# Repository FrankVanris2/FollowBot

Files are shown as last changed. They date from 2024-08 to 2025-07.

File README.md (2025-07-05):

# FollowBot

[Watch the FollowBot Prototype 1 in Action!](https://www.youtube.com/shorts/VBmE77GVLnA)

## Table of Contents
 - [Introduction](#introduction)
 - [About the Team](#about-the-team)
 - [Features](#features)
 - [Design Details](#design-details)
 - [Development Guidelines](#development-guidelines)
 - [Installation](#installation)
 - [Other Resources](#other-resources)
 - [Contributing](#contributing)
 - [License](#license)

## Introduction
Followbot is a companion robot that follows you around. The goal for this project is to build a low-cost robot that can carry you belongings for you. Currently, FollowBot is useful within school/city settings. Future endeavors include developing the capability for FollowBot to traverse uneven terrain such as dirt of gravel

## About the Team
We are a dedicated group of students committed to making robotics accessible and affordable for everyone. Our goal is to develop innovative robotic solutions that serve those in need while prioritizing safety and minimizing risks to humans. Through ethical engineering and thoughtful design, we strive to advance robotics in a way that benefits society and ensures responsible technological progress.
### Team at the Park
TeamAtThePark_1
### Close-up with the Robot
TeamCloseToRobot
### Buiding the Future

### Probem-Solving in Action


## Features
- Carry up to 50 lbs
- Mapping capabilities to traverse from one point to another
- Following mechanics
- Companion app and website to monitor and control robot remotely

## Design Details
The construction of the FollowBot presents a significant challenge, given the intricate engineering required to create a device capable of carrying and autonomously following a user. The hardware components and their assembly will demand meticulous attention and precision.

On the hardware side we are utilizing the Arduino Uno Rev4 in order to send and do important tasks for the user. We will be developing a webpage and an app with valuable information for the user to use when needed. Mapping capabilities and path-finding algorithms will be applied to the FollowBot in order to avoid obstacles while following a designated path to a specific location. Computer vision techniques will be used to allow the FollowBot to follow the user if needed in order for it to carry their belongings. Sensors such as LiDAR, RGB etc. will come with software that will allow us to really improve the machine learning models that we will apply.

In terms of project success, our primary focus will be on systematic organization and incremental prototyping. We plan to develop a prototype during the first quarter and progressively refine it. Our goal is to deliver a practical and beneficial product for any consumer seeking a FollowBot to carry their belongings or allow the FollowBot to go to designated places.

### High Level Design Architecture
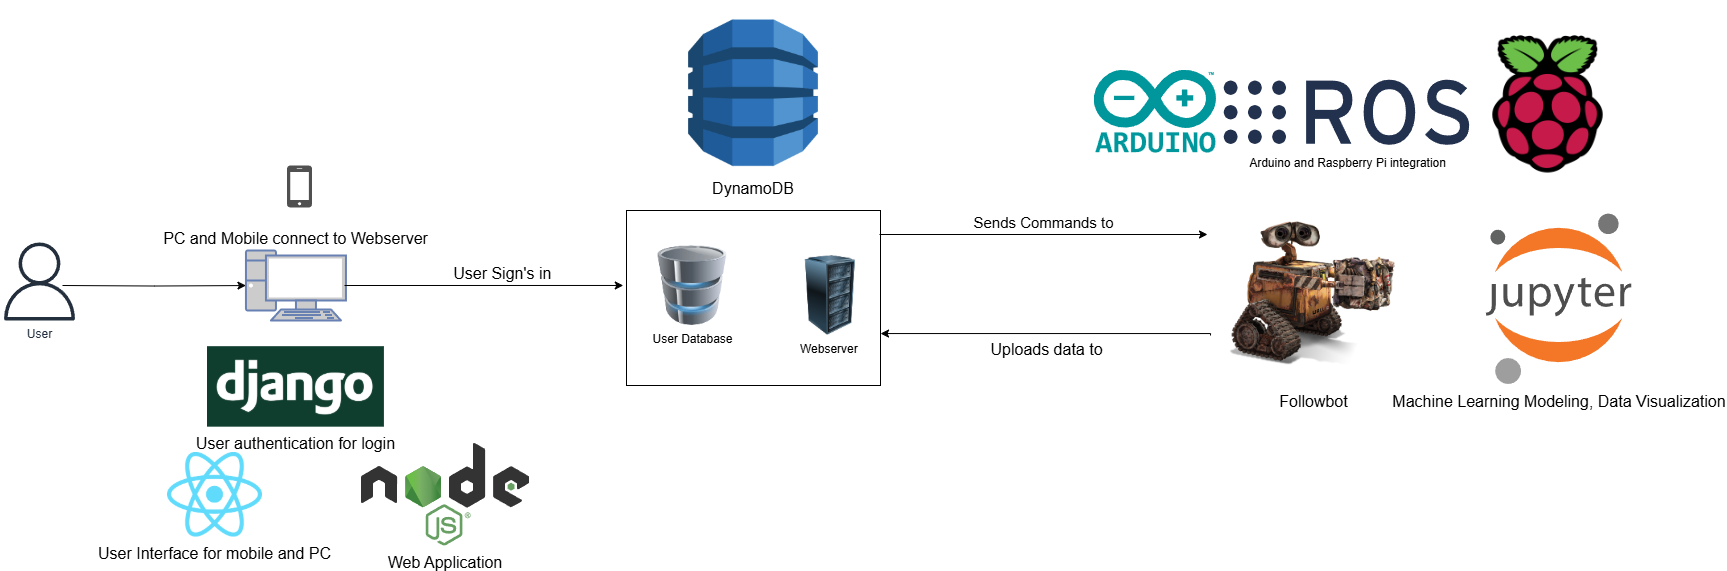
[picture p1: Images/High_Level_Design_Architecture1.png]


## Development Guidelines

### MANDATORY: Unit Testing Before Implementation

**Every developer MUST implement comprehensive unit tests before adding any new feature to the codebase, regardless of framework or repository.**

#### Testing Requirements:

1. **Write Tests First**: Follow Test-Driven Development (TDD) principles
   - Write failing tests that describe the expected behavior
   - Implement the minimum code to make tests pass
   - Refactor while keeping tests green

2. **Test Coverage Requirements**:
   - All new functions/methods must have corresponding unit tests
   - Minimum 80% code coverage for new features
   - Test both success and failure scenarios
   - Mock external dependencies (server calls, hardware interfaces)

3. **Framework-Specific Testing Standards**:
   - **Arduino/PlatformIO**: Use PlatformIO's built-in testing framework
   - **Python Backend**: Use Python's unittest or pytest
   - **JavaScript/React**: Use Jest for components and API functions
   - **C++ FollowBot Code**: Use PlatformIO native testing
   - Follow naming convention: `test_[function_name]_[scenario]`
   - Include setup and teardown for test isolation

4. **Before Pull Request**:
   ```bash
   # For Arduino/PlatformIO projects
   pio test
   
   # For Python backend
   python -m pytest
   
   # For JavaScript projects
   npm test
   
   # Verify build still works
   pio run  # For Arduino
   python -m py_compile *.py  # For Python
   npm run build  # For JavaScript
   ```

5. **Test Documentation**:
   - Document test scenarios in commit messages
   - Update test documentation when adding new test patterns
   - Reference our testing documentation: [Running Unit Tests PlatformIO](./Documentation/RunningUnitTestsPlatformIO.md)

**⚠️ CRITICAL**: No feature implementation should be merged without corresponding unit tests. This applies to all repositories in the FollowBot ecosystem, including the main robotics code, web applications, and mobile apps.

# Installation

## Installation Steps
Before you clone your repo you will need to first download vscode. The reason being is that when developing on the Robotics side There is a nice extension that is not found in any other IDE's. To make your life
easier and for you to not try and configure PlatformIO on another IDE with hassle. I would absolutely advise you to download VSCode.

* In VSCode click the extensions icon.

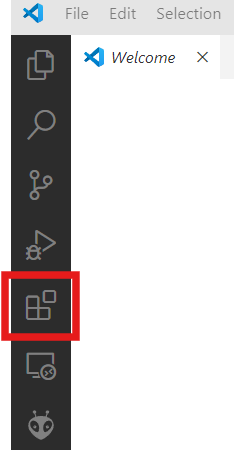
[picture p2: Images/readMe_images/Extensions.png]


* Look up **PlatformIO IDE**

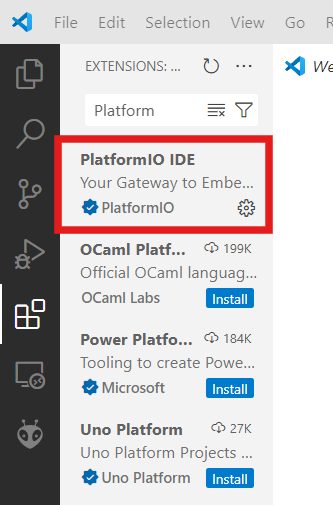
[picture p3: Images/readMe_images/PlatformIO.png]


* Install it

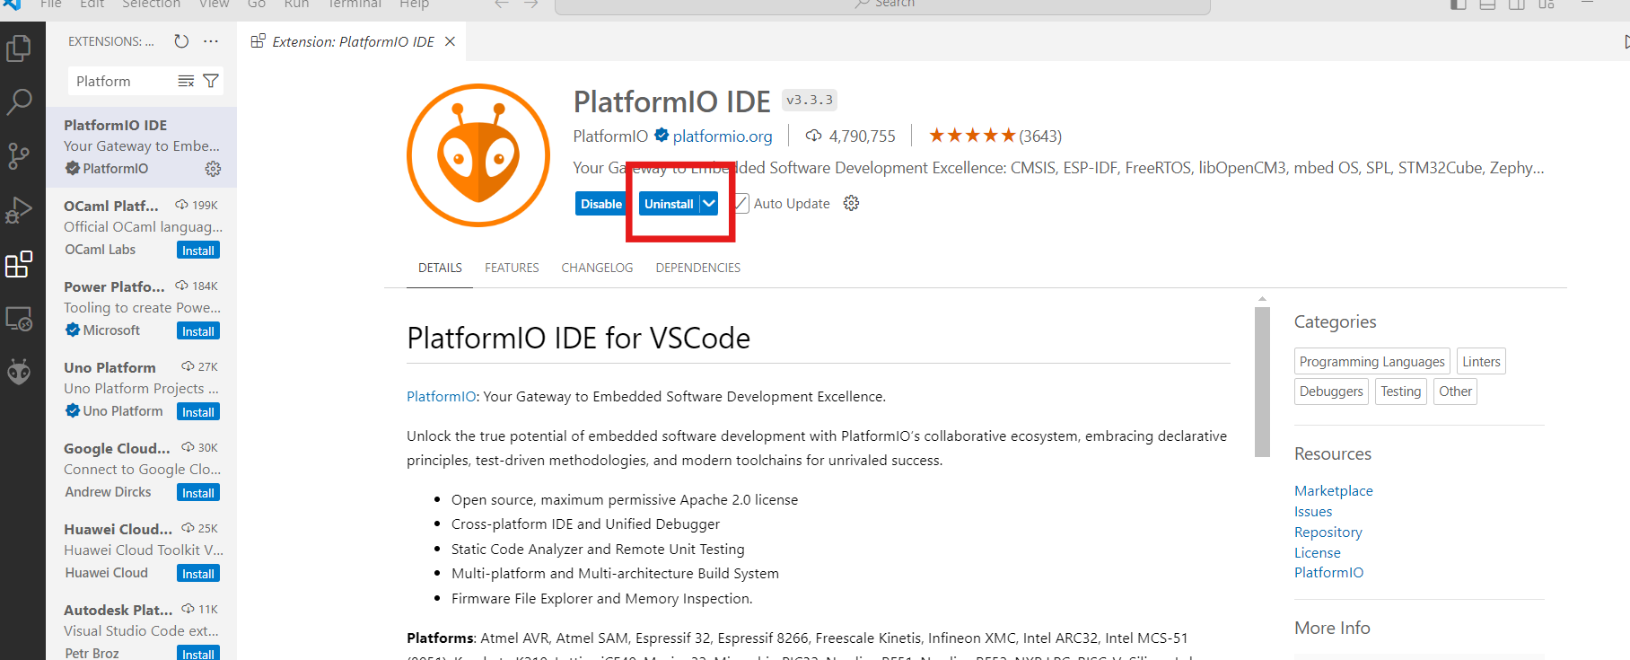
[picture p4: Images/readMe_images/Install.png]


After VSCode with the PlatformIO extension has been installed we can now git clone the repo.

## Other Resources

## Website development
The website development has been migrated to it's very own repository, same will occur for the Native React side. If you want to learn more about the website development for this project, please check out the link 
below. Many changes within this repository will continue to occur throughout our production, along with our refactoring of our project:

[Website Development for Followbot](https://github.com/FrankVanris2/FollowBotWebsite)

## Robotic-end
The robotic side of this project will involve the integration and communication between an Arduino board and a Raspberry Pi running ROS2. The Arduino board will facilitate motor and sensory communication by allowing messages to be sent back and forth, enabling various applications supported by the Raspberry Pi with ROS2. Utilizing ROS2, we can develop learning models and employ computer vision technologies to enhance the accuracy of our mapping, following mechanics, voice recognition, path-finding, and user recognition. The required steps in order to begin development on the robotic side of this project is found in the link below. It will direct you to another Repository that will connect back as always to our master repository:

[ROS2 Development for FollowBot](https://github.com/FrankVanris2/ROS2_FollowBot)

**For Arduino Development**:
* If you have not already please download VSCode with the PlatformIO extension in order for you to develop on the Robotic side.
* Within the PlatformIO homepage there are 4 side buttons that you will be allowed to click on. Please click on the `Open Project` Button

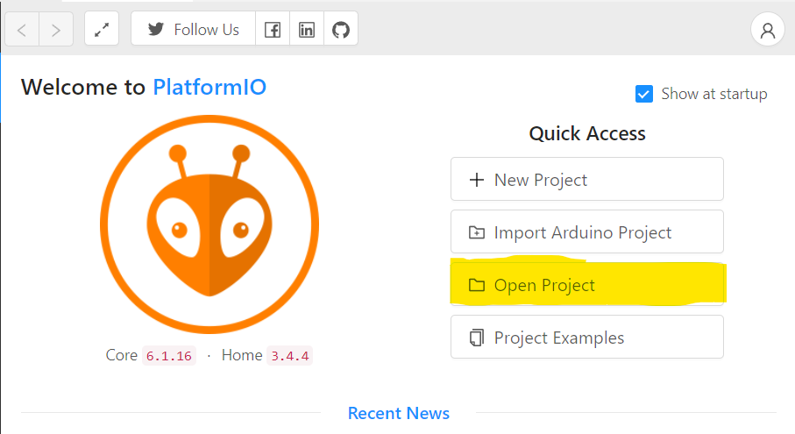
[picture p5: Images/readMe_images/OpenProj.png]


* When you do so please go where you placed your repo, and you will need to open this folder: `FollowBot->FollowBot`

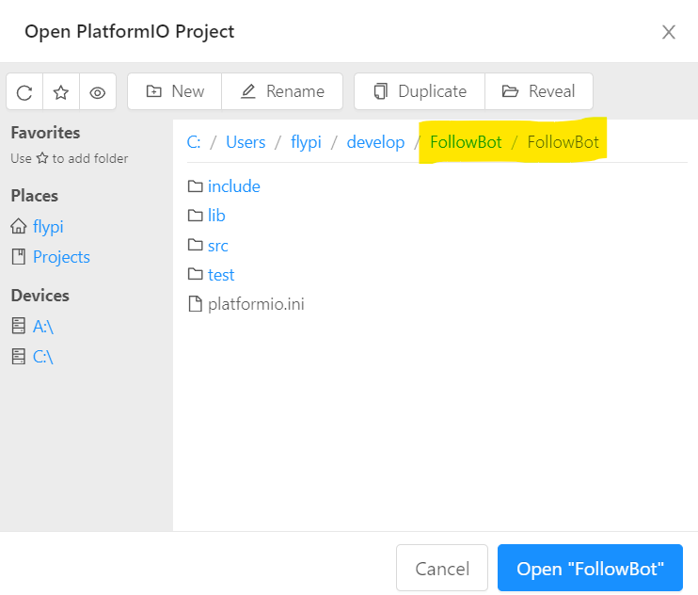
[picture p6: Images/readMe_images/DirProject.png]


* After you do so you will see all the files that we have made for the development of FollowBot.
* To run it you will need to press the blue checkmark icon at the bottom of the screen



* To push and build the code on the Arduino board or any Microcontroller that is applicable press the arrow icon at the bottom of the screen



* When you are programming on the device, sometimes you will want to print something to the Serial port. Click the plug icon to open the Serial Monitor.



* When you need to input PlatformIO specific commands, you will need to open the IO terminal. The icon is a small cmd screen.



## Other Documentation:

Within the Repo there is a directory called `Documentation` Most of the documentation is around the requirements and the design of our Project. But there is specific docs that I recommend you guys reading up on. Please read the `RunningUnitTestsPlatformIO` documentation

- [Running Unit Test PlatformIO](https://github.com/FrankVanris2/FollowBot/blob/main/Documentation/RunningUnitTestsPlatformIO.md)
  
## Contributing
We are a small team of college students, any help is appreciated! You can clone the repository on GitHub and submit a pull request.
```sh
git clone https://github.com/FrankVanris2/FollowBot.git
```

## License
MIT License 

Copyright (c) 2024 Trong Duong, Joeseph Hoang, Igor Janotti, Frank Vanris

Permission is hereby granted, free of charge, to any person obtaining a copy of this software and associated documentation files ("Followbot") to deal in the Software without restriction, including without limitation the rights to use, copy, modify, merge, publish, distribute, sublicense, and/or sell copies of the Software, and to permit persons to whom the Software is furnished to do so, subject to the following conditions:

The above copyright notice and this permission notice shall be included in all copies or substantial portions of the Software.

THE SOFTWARE IS PROVIDED “AS IS”, WITHOUT WARRANTY OF ANY KIND, EXPRESS OR IMPLIED, INCLUDING BUT NOT LIMITED TO THE WARRANTIES OF MERCHANTABILITY, FITNESS FOR A PARTICULAR PURPOSE AND NONINFRINGEMENT. IN NO EVENT SHALL THE AUTHORS OR COPYRIGHT HOLDERS BE LIABLE FOR ANY CLAIM, DAMAGES OR OTHER LIABILITY, WHETHER IN AN ACTION OF CONTRACT, TORT OR OTHERWISE, ARISING FROM, OUT OF OR IN CONNECTION WITH THE SOFTWARE OR THE USE OR OTHER DEALINGS IN THE SOFTWARE.

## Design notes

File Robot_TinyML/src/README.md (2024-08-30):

<h1>TinyML for FollowBot</h1>

Creating a tiny Machine Learning Model that will be used in order to obtain
predictions throughout the obtained historical data of battery life, distance, temperature,
and motor control.

<h2> Important mechanics </h2>

* everywhereml (used for converting learning models to cpp files for Arduino).
* tinyML offers me to use specific learning models applicable to the Arduino board.

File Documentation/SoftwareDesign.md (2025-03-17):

<h1>Software/Hardware Design Document <br>
for <br>
Follow Bot</h1>

<h2> Version 1.0 approved<br>
<br>
Prepared by Frank Vanris, Igor Janotti, Trong Duong, Joseph Hoang<br><br>
Bellevue College<br><br>
7/10/2024<br><br></h2>

<h2>
1. Introduction <br> <br>
</h2>

<h3> 1.1 Purpose<br> </h3>
This software/hardware design document describes the architecture and system design of the Follow Bot FollowBot as well as it's software, and how reliable and usable it will be for the user.<br><br>

<h3> 1.2 Scope <br> </h3>
The Goal for this FollowBot is for the user to be able to use it wherever they go while storing their belongings in a safe and reliable place. As well as map it to specific locations in order to bring items from place to place.<br><br>

<h3> 1.3 Overview <br></h3>
The main gist of this document is to explain and express how the design for this software/hardware will be handled and to explain how the user will be able to use our software and hardware efficiently and reliably.<br><br>

<h3> 1.4 Reference Material <br> </h3>
Here are the given sources that were used to relay information for this document:<br>

* https://onlinelibrary.wiley.com/doi/10.1155/2022/8274455
* https://docs.ros.org/en/jazzy/index.html
* https://docs.wpilib.org/en/stable/docs/hardware/hardware-basics/index.html
* https://docs.wpilib.org/en/stable/docs/software/hardware-apis/motors/index.html
* https://docs.arduino.cc/
* https://wiki.freecad.org/
* https://www.klipper3d.org/
* https://legacy.reactjs.org/docs/getting-started.html
* https://www.nature.com/articles/s41598-023-33837-1
* https://tinyurl.com/yc5y6r9x (AWS)
* https://scikit-learn.org/stable/ 

<h4> Books: </h4>

* Practical Robotics in C++ By *Lloyd Brombach*
* An Introduction to AI Robotics By *Robin Murphy*
* Introduction to Robotics: Mechanics and Control By *John J Craig*
* A Concise introduction to FollowBot Programming with ROS2 By *Francisco Rico Manrique*

<h3> 1.5 Definitions and Acronyms <br> </h3>

* ROS: Robotics Operating System

* DC: Direct Current

* AC: Alternating Current

* Nodes: A participant in the ROS2 Graph, which uses a client library to communicate with other nodes.

* Topics: one of the three main ways that nodes can communicate with one another is via topics.

* Jazzy: The newest version of the ROS2 of the creation of this document, there are other versions such as Jammy, Foxy, Humble, Iron, and others.

* Motor Drivers: control chips that are meant to run current through a number of motors.

* Motor Controller: Any Microcontroller that controls motors in general, such as Arduinos, ESP32's and AdaFruit controllers.

* AP: Access Points

* WiFi Triangulation: A way for wifi routers, to triangulate a position.

* Arduino: a microcontroller

* ESP32: a microcontroller
<br>

## 2. System Overview

### App

#### Goal
The goal is to have the app update you on specific features that the FollowBot contains such as battery, weight, temperature, distance, and much more. With the app you will be able to map the FollowBot to a specific location. Or call the FollowBot to come to your specific location. There are many applications that the app will bring, and much more to come after.

#### Requirements

- **Light and Dark Mode**  
  The app should support both light and dark themes for user interface customization.

- **FollowBot Mapping Feature**  
  The app will allow the FollowBot to go to a specific location, or traverse to your location.

- **FollowBot Status Updates**  
  The app will update the FollowBot's status every 30 seconds. The update will include:
  - Power level
  - Temperature
  - Weight of the FollowBot
  - Information on any movement issues related to the weight
  - Distance between the user and the FollowBot when it comes to following mechanics.

- **Distance Notifications**  
  The app will send notifications if the FollowBot gets too far away from the user.

**Damage Notifications**
 Notifications for any possible damages that occurred on the FollowBot. Such as movement control changes, Temperature unresponsive changes, weight unresponsive changes, and power unresponsive changes. As well as network unresponsive changes.

- **Controller Functionality**  
  The app will act as a controller for the FollowBots, using the touchscreen. 
  - Optionally, a game controller can be used if the touchscreen is not functional.

### Website

#### Goal
The goal of the website is to inform the users about what the FollowBot does and send queries back to the owners of the website. It will contain as well demo features that the user will be able to try out with their FollowBot. And the website will contain a forums page in order for users alike to ask questions that are related to FollowBot

#### Requirements

- **Technologies**  
  The website will be written in JavaScript, HTML, and CSS.

- **Light and Dark Mode**  
  The website will support both light and dark modes for user interface customization.

- **Pages**  
  The website will contain four main pages:
  
  1. **FollowBot**  
     - This page will include text and an embedded video from YouTube.
  
  2. **App**  
     - This page will include text, an embedded video from YouTube, and a link to download the app.
  
  3. **About Us**  
     - This page will include text and links to our work and social media profiles.
  
  4. **Feedback**  
     - This page will include a text area where users can provide feedback.
     - A private section for owners will be available to download and delete messages.
     - Consider using a database to store and manage feedback submissions.

  5. 

### Robotic Overview

#### Goal
The goal of the FollowBot is for it to carry up to 50 lbs of your belongings and follow the user while avoiding obstacles. FollowBot will also be able to map to a specific location as well as meet your specific position.

We will be experimenting with different kinds of motors, sensors, and modules to determine the best way for the FollowBot to follow the user while maneuvering through obstacles quickly. We also aim to create a device that keeps costs to a minimum, as well as find ways to have FollowBot map between two locations..
We will be experimenting with different kinds of motors, sensors, and modules to determine the best way for the FollowBot to follow the user while maneuvering through obstacles quickly. We also aim to create a device that keeps costs to a minimum.

#### Weight Carrying and Following
The user will be able to place various belongings within the device, such as food, electronics, books, sports items, clothing, and more. The FollowBot will be able to track the user based on it's 

#### Sensors
The FollowBot will use multiple sensors to avoid and move away from obstacles. Forms of avoidance will include lidar sensors, computer vision, and echo locative tracking. The choice of sensors will be decided as a team based on their accuracy in avoiding obstacles quickly.

#### Mapping
The FollowBot will be able to map out a path to a given location through API tools such as Google Maps, BC's directed Map API, and much more.
The FollowBot will use multiple sensors to avoid and move away from obstacles. Forms of avoidance will include lidar sensors, computer vision, and echo locative tracking. The choice of sensors will be decided as a team based on their accuracy in avoiding obstacles quickly.

#### Hardware
When designing the hardware, cost will be a key consideration. Initially, hardware will be created through 3D printing and simple woodworking. Designing the hardware will be done using various design applications such as FreeCAD, Fusion360, and Blender. For electronic hardware development and wiring, the final design will be created via a PCB manufacturer.

#### Real-Time Updates
Through the mobile app, the FollowBot will provide real-time updates on battery life, distance between the user and the FollowBot, the temperature within the FollowBot's capsule, and the weight distribution on the FollowBot. Notifications will be sent to the user if the battery life is low or if the FollowBot needs help or repair.

#### Machine Learning Models
We aim to add machine learning to the FollowBot. The capability for the FollowBot to learn from its mistakes through reinforcement learning could be beneficial in improving performance while conserving battery life. Our goal is to maximize battery life so the FollowBot can be used daily without frequent charging. As well as finding best possible paths to better improve the following mechanics of FollowBot.

#### Authentication/Security
We plan to add an authentication process when initializing the FollowBot on the user's account through the mobile app and the website. Each FollowBot will have a unique secure number configuration that cannot be changed. This configuration will only need to be done once.

#### Cost
We aim to keep the price range for the FollowBot under $500, ideally under $300. The device should be stable, useful, and beneficial to the consumer. The cost should attract consumers to buy our product. Our goal is to ensure the device is worth their money and to exceed their expectations.

###### UPDATE 

#### Demo GOALS
We aim to have multiple demos for FollowBot and  we consider FollowBot passing the demos as succesfully goal

### Demo 1
First demo getting information from FollowBot, 

### Demo 2
Second demo controlling the FollowBot from using website,

### Demo 3
Third demo moving circle while avoiding obsticles

<h2>3. Robotic Architecture</h2>

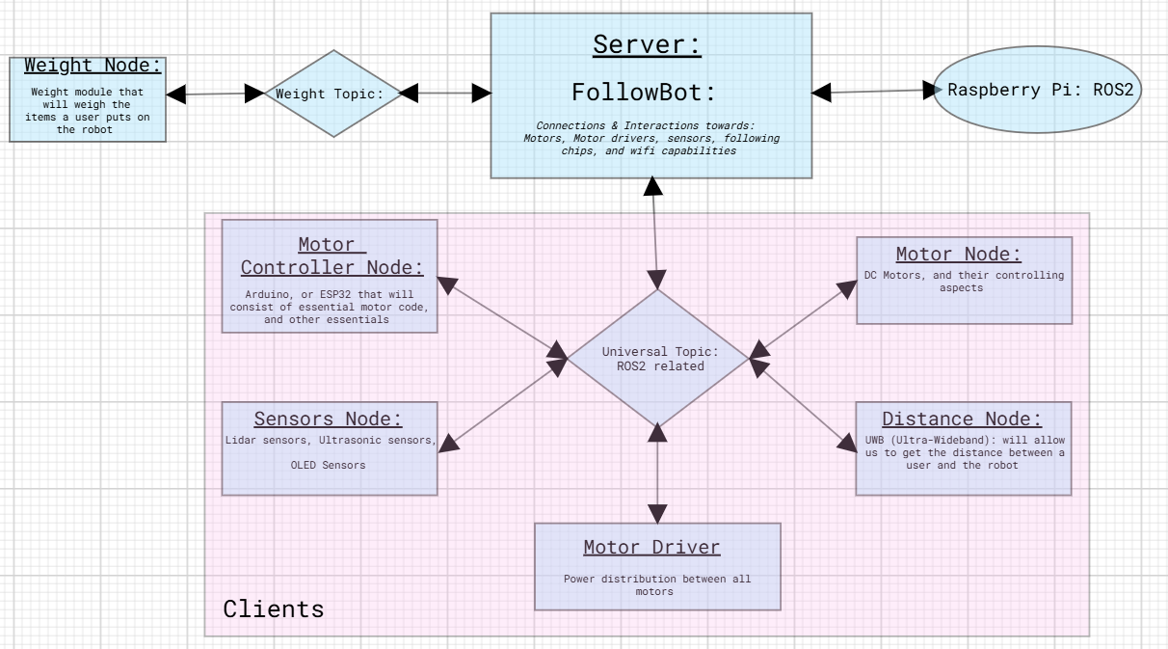
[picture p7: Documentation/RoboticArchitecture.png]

*FollowBot Architecture*

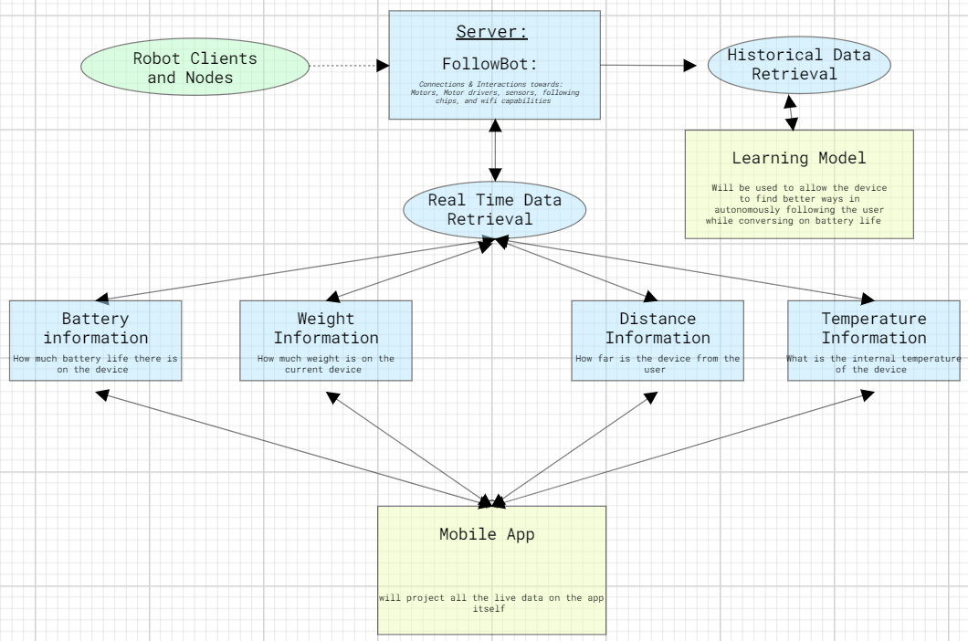
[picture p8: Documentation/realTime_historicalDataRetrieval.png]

*Data Retrieval for app and learning model*
 
 <h2>3. Systems Architecture:</h2>

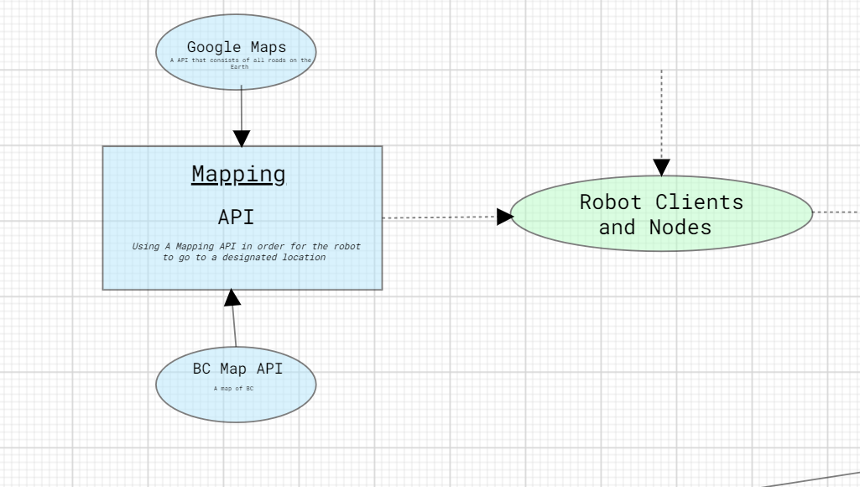
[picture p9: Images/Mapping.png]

*Mapping*

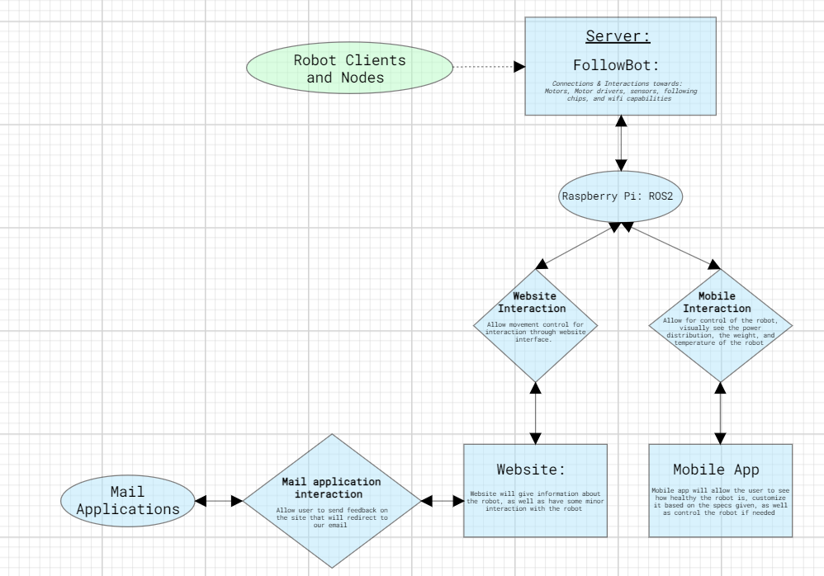
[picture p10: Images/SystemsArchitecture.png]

*Interaction between website app and FollowBot*

*Interaction between website app and FollowBot*

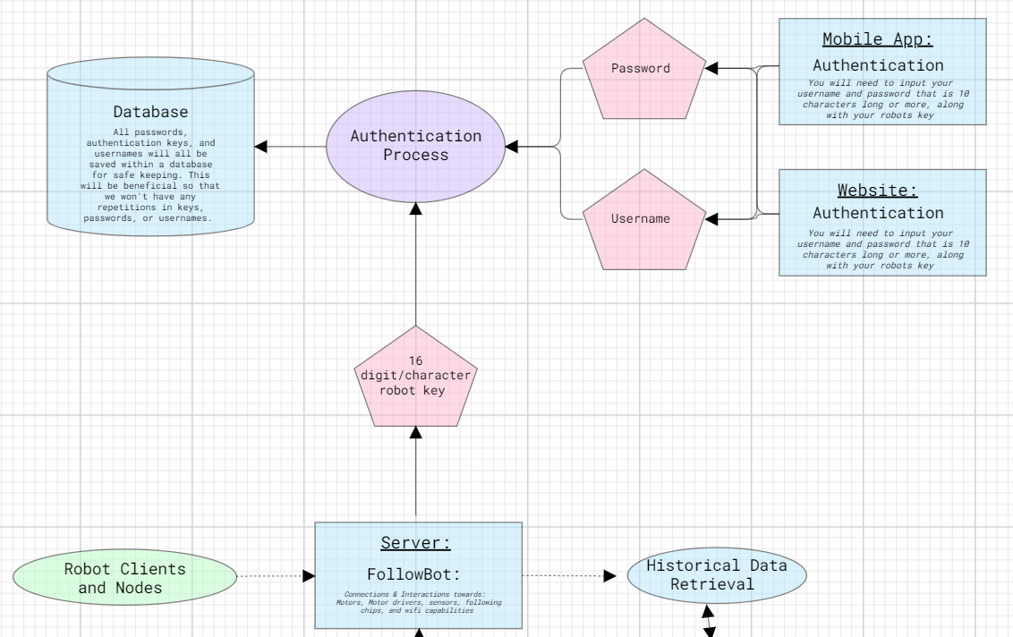
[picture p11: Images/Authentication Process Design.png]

*Authentication process for FollowBot *

*Authentication process for FollowBot*

<h2>Architectural Design for both Robotic and System sides: </h2>

<h3> FollowBot Architectural Design </h3>

<h4> 3.1 FollowBot Architecture </h4>
1. FollowBot Server:

  * FollowBot server takes place within the ROS2 Raspberry Pi.
  * allows information back and forth between client nodes.

2. Universal Topic:
    
    * Universal topic allows for message transferring and message retrieving between client and server nodes.

3. Client Nodes:

    a. Motor Controller Node:

        * Control motor movement and allow for mathematical calculations between movements between a point to another point
    
    b. Sensors Node:
        
        * Object detection, and avoidance sensors such as Lidar, supersonic
        and others. Messaging server when close to object or far from object.
    
    c. Motor Driver Node:

        * Allows control for the motors and will allow speed control for the motor controller as well as battery life control.
    
    d. Distance Node:

        * This will allow for identifying the distance between a point to another point in space.

    e. Motor Node:

        * Motor control and power supply to the motors itself.

4. External Weight Node:
    * This node is seperate from the others because this will instantly connect to the mobile device in order to give live data of how much weight is being stored on the device itself.
<br><br>

<h4>Data Retrieval and Learning Model Architecture </h4>

1. FollowBot Client:
1. FollowBot Server:

    * FollowBot client takes place in the FollowBot 
    * A python server is used to send information back and forth between the user and the FollowBot.

2. Real Time Data Retrieval:
    * A method that will be used to obtain live data from the FollowBot.
    * live data varies from battery life, to weight gain.

3. Data:
    
    **Battery Information**: Will give you how much battery is left in the system.

    **Weight Information**: Will give you the amount of weight that is being stored on the system.

    **Distance Information**: Will give the proximity and distance between you and the FollowBot.

    **Temperature Information**: Will give you the interior temperature of where you are storing your items. Will be beneficial due to the fact that people are buying groceries and do not want their items to get spoiled.

4. Mobile App:
    * Will visually show the real time data to the user when they are using the app as well as allow the user to direct itself from point A to B from a Map.
  
5. Learning Model:
    * Will be used to take in past data of the FollowBot  in order to find better ways to correct it's movement properly so it can easily, safely, and quickly follow you while trying to reduce battery consumption. 
    * Will be used to take in past data of the FollowBot in order to find better ways to correct it's movement properly so it can easily, safely, and quickly follow you while trying to reduce battery consumption.
<br><br>

<h3> 3.1 Systems Architectural Design </h3>

<h4> Mobile and Web Application Interaction </h4>

1. Server AWS:
    * We know that this will consist of all the connections to the client nodes, but it will also connect between the mobile app and the website itself.
  
2. ROS2 Raspberry Pi or Microcontroller:
    * This device consists of all the fundamental backends in order to connect to the Server which will connect to the website and mobile app. Mapping features will be also added as well.

3. Website interaction:
    * Backend to frontend interaction between the website server and FollowBot and vice versa.
    * With the website you will be able to also control the FollowBot itself by connecting to it if it is yours.

4. Website:
    * The website will consist of reliable information about the FollowBot as well as have some minor interaction with the FollowBot.

5. Mobile interaction:
    * Backend to frontend interaction between the mobile app and the Raspberry pi
    * The mobile app will have the main control over the FollowBot itself, and will display reliable information about the FollowBot

6. Mobile App:
    * You will be able to interact with the FollowBot through a mobile interface. It will allow you to see certain specs such as battery, temperature, weight, and distance. You will also be able to control the FollowBot if needed.

7. Mail Application interaction:
    * There will be an interaction from frontend to frontend for for sending information to users who have purchased FollowBot. Updates will correlate to mobile related features, FollowBot related features, and much more.

8. Mail Application:
    * The owner of the website will recieve emails from users that use the feedback page on the website. This will allow owners of the website to gain reliable information based on issues or future add-ons for the FollowBot.

9. Forums Page:
    * Users will be able to open the forums page in order to ask questions or look up questions that are related to FollowBot. Users will be able to communicate with one another, answer questions from one another, and upvote answers to questions based on how reliable they are.
  
<br><br>

<h4> Authentication Process </h4>

1. AWS Server:
1. FollowBot Server:

    * The Server will take place on a AWS instance EC2.
    * Allows information back and forth between client nodes, website, and mobile app.
    * FollowBot server takes place within the ROS2 Raspberry Pi.
    * Allows information back and forth between client nodes.

2. FollowBot  Authentication Key:
    * A 16 number/character key meant for every FolloBobot.
2. FollowBot Authentication Key:
    * A 16 number/character key meant for every FollowBot.
    * Every key will be different from the last. 

3. Mobile App/Website Authentication:
    a. You will input a username.
    b. You will input a password.

4. Authentication process:
    * the combination of the FollowBots key as well as the users password and username will allow them to be authenticated for the use of the FollowBot  and for special offers as well as access towards the guides, feedback page, and support page.
    * the combination of the FollowBots key as well as the users password and username will allow them to be authenticated for the use of the FollowBot and for special offers as well as access towards the guides, feedback page, and support page.

5. Database:
  * The database will be used to store the FollowBots keys, passwords, and usernames of users that are subscribed to the product. The database will be a way of making sure certain keys are not the same from one another as well as passwords and usernames.

<br><br>

<h4> Mapping process </h4>

1. BC Mapping API:
    * We will potentially use the BC map in order to determine the best possible path to a location for the FollowBot
    * The map will allow FollowBot to go to different locations on BC

2. Google Maps:
    * Google maps will allow for full access of mapping for the FollowBot. It will allow FollowBot to go to specific locations from point A to point B.

3. Database:
    * We will contain a Database that will potentially contain most University Campuses maps in order to traverse from point A to point B.
<br><br>

### 3.2 FollowBot Decomposition Architectural Design

#### FollowBot Architecture

1. **FollowBot Server**
    - **Description**: The FollowBot Server operates within the ROS2 Raspberry Pi and facilitates communication between client nodes.
    - **Subsystem Model**:
      - **Class**: `RobotServer`
      - **Attributes**: `serverID`, `status`
      - **Methods**: `initialize()`, `sendMessage()`, `receiveMessage()`
    - **Interface Specifications**:
      - **Interfaces**: `ICommunication`
      - **Methods**: `sendMessage()`, `receiveMessage()`
<br><br>

2. **Universal Topic**
    - **Description**: The Universal Topic enables message transfer and retrieval between client and server nodes.
    - **Subsystem Model**:
      - **Class**: `UniversalTopic`
      - **Attributes**: `topicID`, `messageQueue`
      - **Methods**: `publishMessage()`, `subscribe()`
    - **Interface Specifications**:
      - **Interfaces**: `ITopic`
      - **Methods**: `publishMessage()`, `subscribe()`
<br><br>
3. **Client Nodes**

  a. **Motor Controller Node**

  - **Description**: Controls motor movement and performs mathematical calculations for movement between points.
      
  - **Subsystem Model**:
    - **Class**: `MotorControllerNode`
    - **Attributes**: `controllerID`, `currentPosition`, `targetPosition`
    - **Methods**: `calculatePath()`, `moveToTarget()`
  - **Interface Specifications**:
    - **Interfaces**: `IMotorControl`
    - **Methods**: `calculatePath()`, `moveToTarget()`

  b. **Sensors Node**
      
  - **Description**: Handles object detection and avoidance using sensors like Lidar and supersonic sensors.
  - **Subsystem Model**:
    - **Class**: `SensorsNode`
    - **Attributes**: `sensorID`, `objectDistance`
    - **Methods**: `detectObject()`, `sendAlert()`
  - **Interface Specifications**:
    - **Interfaces**: `ISensor`
    - **Methods**: `detectObject()`, `sendAlert()`

  c. **Motor Driver Node**

  - **Description**: Controls the motors, including speed and battery life management.

  - **Subsystem Model**:
    - **Class**: `MotorDriverNode`
    - **Attributes**: `driverID`, `motorSpeed`, `batteryLevel`
    - **Methods**: `controlSpeed()`, `monitorBattery()`
  - **Interface Specifications**:
      - **Interfaces**: `IMotorDriver`
      - **Methods**: `controlSpeed()`, `monitorBattery()`

  d. **Distance Node**

  - **Description**: Identifies the distance between points in space.

  - **Subsystem Model**:
    - **Class**: `DistanceNode`
    - **Attributes**: `distanceID`, `startPoint`, `endPoint`
    - **Methods**: `calculateDistance()`
  - **Interface Specifications**:
    - **Interfaces**: `IDistance`
    - **Methods**: `calculateDistance()`

  e. **Motor Node**

  - **Description**: Manages motor control and power supply.
      
  - **Subsystem Model**:
    - **Class**: `MotorNode`
    - **Attributes**: `motorID`, `powerSupply`
    - **Methods**: `controlMotor()`
  - **Interface Specifications**:
    - **Interfaces**: `IMotor`
    - **Methods**: `controlMotor()`

  f. **External Weight Node**
    
    - **Description**: Connects to a mobile device to provide live data on the weight being stored on the device.
    - **Subsystem Model**:
      - **Class**: `ExternalWeightNode`
      - **Attributes**: `weightID`, `currentWeight`
      - **Methods**: `connectToDevice()`, `sendWeightData()`
    - **Interface Specifications**:
      - **Interfaces**: `IWeight`
      - **Methods**: `connectToDevice()`, `sendWeightData()`

<br><br>

#### Data Retrieval and Learning Model Architecture

1. **AWS Server**
    - **Description**: The FollowBot  Server operates within the AWS Instance and facilitates communication between client nodes.
1. **FollowBot Server**
    - **Description**: The FollowBot Server operates within the ROS2 Raspberry Pi and facilitates communication between client nodes.
    - **Subsystem Model**:
      - **Class**: `AWSServer`
      - **Attributes**: `serverID`, `status`
      - **Methods**: `initialize()`, `sendMessage()`, `receiveMessage()`
    - **Interface Specifications**:
      - **Interfaces**: `ICommunication`
      - **Methods**: `sendMessage()`, `receiveMessage()`

2. **Real Time Data Retrieval**
    - **Description**: A method used to obtain live data from the FollowBot. The live data varies from battery life to weight gain and more.
    - **Description**: A method used to obtain live data from the FollowBot. The live data varies from battery life to weight gain.
    - **Subsystem Model**:
      - **Class**: `RealTimeDataRetrieval`
      - **Attributes**: `dataID`, `batteryLife`, `weightGain`, `timestamp`
      - **Methods**: `retrieveBatteryLife()`, `retrieveWeightGain()`, `updateTimestamp()`
    - **Interface Specifications**:
      - **Interfaces**: `IDataRetrieval`
      - **Methods**: `retrieveBatteryLife()`, `retrieveWeightGain()`, `updateTimestamp()`

3. **Data**
    - **Description**: Provides various types of information about the FollowBot.
    - **Subsystem Model**:
      - **Class**: `Data`
      - **Attributes**: `batteryInfo`, `weightInfo`, `distanceInfo`, `temperatureInfo`
      - **Methods**: `getBatteryInfo()`, `getWeightInfo()`, `getDistanceInfo()`, `getTemperatureInfo()`
    - **Interface Specifications**:
      - **Interfaces**: `IData`
      - **Methods**: `getBatteryInfo()`, `getWeightInfo()`, `getDistanceInfo()`, `getTemperatureInfo()`

4. **Mobile App**
    - **Description**: Visually shows the real-time data to the user when they are using the app.
    - **Subsystem Model**:
      - **Class**: `MobileApp`
      - **Attributes**: `appID`, `realTimeData`
      - **Methods**: `displayRealTimeData()`
    - **Interface Specifications**:
      - **Interfaces**: `IMobileApp`
      - **Methods**: `displayRealTimeData()`

5. **Learning Model**
    - **Description**: Takes in past data of the FollowBot to find better ways to correct its movement, ensuring it can follow you easily, safely, and quickly while reducing battery consumption.
    - **Subsystem Model**:
      - **Class**: `LearningModel`
      - **Attributes**: `modelID`, `pastData`
      - **Methods**: `analyzeData()`, `optimizeMovement()`
    - **Interface Specifications**:
      - **Interfaces**: `ILearningModel`
      - **Methods**: `analyzeData()`, `optimizeMovement()`

6. **Mapping**
    - **Description**: Allows FollowBot to go from point A to point B from a Map that is saved on the Database.
    - **Subsystem Model**:
      - **Class**: `Mapping`
      - **Attributes**: `mappingID`, `mapData`
      - **Methods**: `obtainMap()`, `obtainMapPositionA()`, `obtainMapPositionB()`
    - **Interface Specifications**:
      - **Interface**: `IMapping`
      - **Methods**: `obtainMap()`, `obtainMapPositionA()`, `obtainMapPositionB()`

### 3.2 Systems Decomposition Architectural Design

#### Mobile and Web Application Interaction

1. **Server AWS**
    - **Description**: Consists of all the connections to the client nodes and connects the mobile app and the website.
    - **Subsystem Model**:
      - **Class**: `ServerAWS`
      - **Attributes**: `awsID`, `status`
      - **Methods**: `connectToClientNodes()`, `connectToMobileApp()`, `connectToWebsite()`
    - **Interface Specifications**:
      - **Interfaces**: `IConnection`
      - **Methods**: `connectToClientNodes()`, `connectToMobileApp()`, `connectToWebsite()`

2. **ROS2 Raspberry Pi Or Microcontroller**
    - **Description**: Contains all the fundamental backends to connect to the website and the mobile app.
    - **Subsystem Model**:
      - **Class**: `ROS2RaspberryPi`or `Arduino`
      - **Attributes**: `deviceID`, `backendStatus`
      - **Methods**: `initializeBackend()`, `connectToWebsite()`, `connectToMobileApp()`
    - **Interface Specifications**:
      - **Interfaces**: `IBackend`
      - **Methods**: `initializeBackend()`, `connectToWebsite()`, `connectToMobileApp()`

3. **Website Interaction**
    - **Description**: Backend to frontend interaction between the website to server to Raspberry Pi or Microcontroller. Allows control of the FollowBot if nearby.
    - **Description**: Backend to frontend interaction between the website and the Raspberry Pi. Allows control of the FollowBot if nearby.
    - **Subsystem Model**:
      - **Class**: `WebsiteInteraction`
      - **Attributes**: `interactionID`, `websiteStatus`
      - **Methods**: `backendToFrontend()`, `controlRobot()`
    - **Interface Specifications**:
      - **Interfaces**: `IWebsiteInteraction`
      - **Methods**: `backendToFrontend()`, `controlRobot()`

4. **Website**
    - **Description**: Provides reliable information about the FollowBot and allows minor interaction with the FollowBot.
    - **Subsystem Model**:
      - **Class**: `Website`
      - **Attributes**: `websiteID`, `content`
      - **Methods**: `displayInfo()`, `interactWithRobot()`
    - **Interface Specifications**:
      - **Interfaces**: `IWebsite`
      - **Methods**: `displayInfo()`, `interactWithRobot()`

5. **Mobile Interaction**
    - **Description**: Backend to frontend interaction between the mobile app, server and the Raspberry Pi or Microcontroller. The mobile app has main control over the FollowBot.
    - **Subsystem Model**:
      - **Class**: `MobileInteraction`
      - **Attributes**: `interactionID`, `mobileStatus`
      - **Methods**: `backendToFrontend()`, `controlRobot()`
    - **Interface Specifications**:
      - **Interfaces**: `IMobileInteraction`
      - **Methods**: `backendToFrontend()`, `controlRobot()`

6. **Mobile App**
    - **Description**: Allows interaction with the FollowBot through a mobile interface. Displays specs like battery, temperature, weight, and distance. Allows control of the FollowBot.
    - **Subsystem Model**:
      - **Class**: `MobileApp`
      - **Attributes**: `appID`, `specs`
      - **Methods**: `displaySpecs()`, `controlRobot()`
    - **Interface Specifications**:
      - **Interfaces**: `IMobileApp`
      - **Methods**: `displaySpecs()`, `controlRobot()`

7. **Mail Application Interaction**
    - **Description**: Frontend to frontend interaction for sending messages through email to the website owner.
    - **Subsystem Model**:
      - **Class**: `MailAppInteraction`
      - **Attributes**: `interactionID`, `emailStatus`
      - **Methods**: `sendEmail()`
    - **Interface Specifications**:
      - **Interfaces**: `IMailInteraction`
      - **Methods**: `sendMail()`

8. **Mail Application**
    - **Description**: The website owner receives emails from users using the feedback page. Provides reliable information based on issues or future add-ons for the FollowBot.
    - **Subsystem Model**:
      - **Class**: `MailApplication`
      - **Attributes**: `mailID`, `feedback`
      - **Methods**: `receiveEmail()`, `processFeedback()`
    - **Interface Specifications**:
      - **Interfaces**: `IMailApplication`
      - **Methods**: `recieveEmail()`, `processFeedback()`

#### Authentication Process

1. **FollowBot Authentication Key**
    - **Description**: A 16 number/character key meant for every FollowBot. Every key will be different from the last.
    - **Subsystem Model**:
      - **Class**: `RobotAuthKey`
      - **Attributes**: `keyID`, `keyValue`
      - **Methods**: `generateKey()`, `validateKey()`
    - **Interface Specifications**:
      - **Interfaces**: `IAuthKey`
      - **Methods**: `generateKey()`, `validateKey()`

2. **Mobile App/Website Authentication**
    - **Description**: Authentication process involving username and password input.
    - **Subsystem Model**:
      - **Class**: `AuthProcess`
      - **Attributes**: `username`, `password`
      - **Methods**: `inputUsername()`, `inputPassword()`
    - **Interface Specifications**:
      - **Interfaces**: `IAuthProcess`
      - **Methods**: `inputUsername()`, `inputPassword()`

3. **Authentication Process**
    - **Description**: Combines the FollowBot’s key with the user’s password and username for authentication.
    - **Subsystem Model**:
      - **Class**: `Authentication`
      - **Attributes**: `authID`, `robotKey`, `userCredentials()`
      - **Methods**: `authenticateUser()`, `grantAccess()`
    - **Interface Specifications**:
      - **Interfaces**: `IAuthentication`
      - **Methods**: `authenticateUser()`, `grantAccess()`

3. **Database**
    - **Description**: Stores FollowBot keys, passwords, and usernames of users subscribed to the product. Ensures unique keys, passwords, and usernames.
    - **Description**: Stores FollowBot keys, passwords, and usernames of users subscribed to the product. Ensures unique keys, passwords, and usernames.
    - **Subsystem Model**:
      - **Class**: `Databse`
      - **Attributes**: `dbID`, `userData`
      - **Methods**: `storeData()`, `retrieveData()`
    - **Interface Specifications**:
      - **Interfaces**: `IDatabase`
      - **Methods**: `storeData()`, `retrieveData()`

#### Mapping Process

1. **BC Mapping API**
    - **Description**: We will potentially use the BC map to determine the best possible path to a location for the FollowBot.
    - **Subsystem Model**:
        - **Class**: `BCMappingAPI`
        - **Attributes**: `mapData`, `locationPoints`
        - **Methods**: `getOptimalPath()`, `navigateToLocation()`
    - **Interface Specifications**:
        - **Interfaces**: `IMappingAPI`
        - **Methods**: `getOptimalPath()`, `navigateToLocation()`

2. **Google Maps**
    - **Description**: Google Maps will allow for full access to mapping for the FollowBot. It will enable FollowBot to go to specific locations from point A to point B.
    - **Subsystem Model**:
        - **Class**: `GoogleMapsAPI`
        - **Attributes**: `startPoint`, `endPoint`
        - **Methods**: `getDirections()`, `calculateRoute()`
    - **Interface Specifications**:
        - **Interfaces**: `IMappingAPI`
        - **Methods**: `getDirections()`, `calculateRoute()`

3. **Database**
    - **Description**: A Database that will potentially contain most University Campuses' maps to traverse from point A to point B.
    - **Subsystem Model**:
        - **Class**: `CampusMapDatabase`
        - **Attributes**: `campusMapData`, `mapID`
        - **Methods**: `storeMap()`, `retrieveMap()`
    - **Interface Specifications**:
        - **Interfaces**: `IDatabase`
        - **Methods**: `storeMap()`

<h2> 3.3 Design Rationale </h2>
We chose this architecture because we needed something modulus in order to do things properly for the scope of our project. When it comes to the authentication process it was tedious in knowing how we would come about it, but we knew that if we made it modular it would make it less tedious in our side. The way we did it is by creating a Database that the authenticator would interact with in order to generate keys for the FollowBot that would not create replicas based on the ones that are currently on the database. That was one rationale that we chose for this project. 
<br><br>
Another is by keeping the ros2 system on the raspberry pi very interactive between many different pieces of hardware and software. With the ROS2 most of the functionalities that will be introduced will always have to be modulus in order for us to communicate between many different areas of hardware and software. Although we've been consistently using a Microcontroller so switching between the two will depend based on how much modular this project will become. No doubt it will become more modular based on the number of components we will be adding.
<br><br>
We also need to rely on the learning models and the mapping api's in order to see the improvements in following within FollowBot. We will also need to getting the Mapping algorithm working accordingly with the FollowBot  which is keeping an eye on it's surroundings.
<br><br>
The way we structured our decomposition above makes it easier for us to understand how we will simplify yet comprehend how our system should be.

<h2> 4.0 Data Design </h2>

<h3> 4.1 Data Description </h3>
When it comes to data and obtaining historical data for the machine learning model we will be using dataframes in order to store the data properly, ranging from battery life to weight distribution. When it comes to Databases the information will also be stored in a table of data. Other forms of data storing will be used in other applications when it comes to the FollowBot itself

<h3> 4.2 Data Dictionary </h3>

| Object|Attributes|Methods|
|---|---|---|
| **Authentication**| `authID`: String,<br> `robotKey`: String,<br> `userCredentials`: Object| `authenticateUser()`,<br>`grantAccess()`|
| **AuthProcess**| `username`: String,<br> `password`: String| `inputUsername()`,<br> `inputPassword()`|
| **Data**| `batteryInfo`: Float,<br> `weightInfo`: Float,<br> `distanceInfo`: Float,<br> `temperatureInfo`: Float| `getBatteryInfo()`,<br> `getWeightInfo()`,<br> `getDistanceInfo()`,<br> `getTemperatureInfo()`|
| **Database**| `dbID`: String,<br> `userData`: Object| `storeData()`,<br> `retrieveData()`|
| **DistanceNode**| `distanceID`: String,<br> `startPoint`: Object,<br> `endPoint`: Object| `calculateDistance()`|
| **ExternalWeightNode**| `weightID`: String,<br> `currentWeight`: Float| `connectToDevice()`,<br> `sendWeightData()`|
| **LearningModel**| `modelID`: String,<br> `pastData`: Object| `analyzeData()`,<br> `optimizeMovement()`|
| **MailAppInteraction**| `interactionID`: String,<br> `emailStatus`: String| `sendEmail()`|
| **MailApplication**| `mailID`: String,<br> `feedback`: Object| `receiveEmail()`,<br> `processFeedback()`|
| **MobileApp**| `appID`: String,<br> `specs`: Object| `displaySpecs()`,<br> `controlRobot()`|
| **MobileInteraction**| `interactionID`: String,<br> `mobileStatus`: String| `backendToFrontend()`,<br> `controlRobot()`|
| **MotorControllerNode**| `controllerID`: String,<br> `currentPosition`: Object,<br> `targetPosition`: Object | `calculatePath()`,<br> `moveToTarget()`|
| **MotorDriverNode**| `driverID`: String,<br> `motorSpeed`: Float,<br> `batteryLevel`: Float| `controlSpeed()`,<br> `monitorBattery()`|
| **MotorNode**| `motorID`: String,<br> `powerSupply`: Float| `controlMotor()`|
| **RealTimeDataRetrieval**| `dataID`: String,<br> `batteryLife`: Float,<br> `weightGain`: Float,<br> `timestamp`: DateTime| `retrieveBatteryLife()`,<br> `retrieveWeightGain()`,<br> `updateTimestamp()`|
| **FollowBottAuthKey**| `keyID`: String,<br> `keyValue`: String| `generateKey()`,<br> `validateKey()`|
| **AWSServer**| `serverID`: String,<br> `status`: String| `initialize()`,<br> `sendMessage()`,<br> `receiveMessage()`|
| **SensorsNode**| `sensorID`: String,<br> `objectDistance`: Float| `detectObject()`,<br> `sendAlert()`|
| **ServerAWS**| `serverID`: String,<br> `status`: String| `connectToClientNodes()`,<br> `connectToMobileApp()`,<br> `connectToWebsite()`|
| **UniversalTopic**| `topicID`: String,<br> `messageQueue`: Queue| `publishMessage()`,<br> `subscribe()`|
| **Website**| `websiteID`: String,<br> `content`: String| `displayInfo()`,<br> `interactWithRobot()`|
| **WebsiteInteraction**| `interactionID`: String,<br> `websiteStatus`: String| `backendToFrontend()`,<br> `controlRobot()`|

<h2> 5. Component Design </h2>

#### Authentication
- **authenticateUser()**
  - Input: `robotKey`, `userCredentials`
  - Process: Validate `robotKey` and `userCredentials`
  - Output: Authentication status

- **grantAccess()**
  - Input: Authentication status
  - Process: Check if authentication is successful
  - Output: Access granted or denied

#### AuthProcess
- **inputUsername()**
  - Input: `username`
  - Process: Store `username`
  - Output: get access to your account once password is in

- **inputPassword()**
  - Input: `password`
  - Process: Store `password`
  - Output: get access to your account

#### Data
- **getBatteryInfo()**
  - Input: Battery potentiometer counter
  - Process: Retrieve `batteryInfo`
  - Output: `batteryInfo`

- **getWeightInfo()**
  - Input: Weight measurer module
  - Process: Retrieve `weightInfo`
  - Output: `weightInfo`

- **getDistanceInfo()**
  - Input: UWB, Bluetooth, or GPS
  - Process: Retrieve `distanceInfo`
  - Output: `distanceInfo`

- **getTemperatureInfo()**
  - Input: Temperature module
  - Process: Retrieve `temperatureInfo`
  - Output: `temperatureInfo`

#### Database
- **storeData()**
  - Input: `userData`
  - Process: Store `userData` in database
  - Output: None

- **retrieveData()**
  - Input: Query
  - Process: Retrieve data from database
  - Output: `userData`

#### DistanceNode
- **calculateDistance()**
  - Input: `startPoint`, `endPoint`
  - Process: Calculate distance between `startPoint` and `endPoint`
  - Output: Distance

#### ExternalWeightNode
- **connectToDevice()**
  - Input: Device ID
  - Process: Establish connection to device
  - Output: Connection status

- **sendWeightData()**
  - Input: `currentWeight`
  - Process: Send `currentWeight` to device
  - Output: None

#### LearningModel
- **analyzeData()**
  - Input: `pastData`
  - Process: Analyze `pastData`
  - Output: Analysis results

- **optimizeMovement()**
  - Input: Analysis results
  - Process: Optimize FollowBot movement
  - Output: Optimized movement parameters

#### MailAppInteraction
- **sendEmail()**
  - Input: Email content
  - Process: Send email to website owner
  - Output: Owner recieves email from users message input

#### MailApplication
- **receiveEmail()**
  - Input: None
  - Process: Receive email from users
  - Output: Email content

- **processFeedback()**
  - Input: Email content
  - Process: Analyze feedback
  - Output: Feedback analysis

#### MobileApp
- **displaySpecs()**
  - Input: `specs`
  - Process: Display `specs` on mobile app
  - Output: None

- **controlFollowBot()**
  - Input: Control commands
  - Process: Send control commands to FollowBot
  - Output: FollowBot could move or follow a set of tasks

#### MobileInteraction
- **backendToFrontend()**
  - Input: Backend data
  - Process: Transfer data to frontend
  - Output: Data transfer successful or not

- **controlFollowBot()**
  - Input: Control commands
  - Process: Send control commands to FollowBot
  - Output: FollowBot executes those commands

#### MotorControllerNode
- **calculatePath()**
  - Input: `currentPosition`, `targetPosition`
  - Process: Calculate path from `currentPosition` to `targetPosition`
  - Output: Path

- **moveToTarget()**
  - Input: Path
  - Process: Move motor along path
  - Output: motor turns on in order to move towards target

#### MotorDriverNode
- **controlSpeed()**
  - Input: Speed value
  - Process: Adjust motor speed
  - Output: motors speed is adjusted

- **monitorBattery()**
  - Input: Battery potentiometer reading
  - Process: Monitor battery level
  - Output: `batteryLevel`

#### MotorNode
- **controlMotor()**
  - Input: Control commands
  - Process: Execute motor control commands
  - Output: motor commands are executed

#### RealTimeDataRetrieval
- **retrieveBatteryLife()**
  - Input: Battery potentiometer current data reading
  - Process: Retrieve current battery life
  - Output: `batteryLife`

- **retrieveWeightGain()**
  - Input: Weight Module
  - Process: Retrieve current weight gain
  - Output: `weightGain`

- **updateTimestamp()**
  - Input: None
  - Process: Update timestamp of data retrieval
  - Output: `timestamp`

#### FollowBotAuthKey
- **generateKey()**
  - Input: None
  - Process: Generate a new authentication key
  - Output: `keyValue`

- **validateKey()**
  - Input: `keyValue`
  - Process: Validate the authentication key
  - Output: Validation status

#### AWSServer
- **initialize()**
  - Input: None
  - Process: Initialize the FollowBot server
  - Output: Initialization status

- **sendMessage()**
  - Input: Message
  - Process: Send message to client nodes
  - Output: nodes recieves message

- **receiveMessage()**
  - Input: None
  - Process: Receive message from client nodes
  - Output: Message

#### SensorsNode
- **detectObject()**
  - Input: Lidar sensors, light sensors, etc.
  - Process: Detect object using sensors
  - Output: Object detection status

- **sendAlert()**
  - Input: Object detection status
  - Process: Send alert when object is detected
  - Output: Stop or avoid obstacle when object is detected

#### ServerAWS
- **connectToClientNodes()**
  - Input: None
  - Process: Connect to client nodes
  - Output: Connection status

- **connectToMobileApp()**
  - Input: None
  - Process: Connect to mobile app
  - Output: Connection status

- **connectToWebsite()**
  - Input: None
  - Process: Connect to website
  - Output: Connection status

#### UniversalTopic
- **publishMessage()**
  - Input: Message
  - Process: Publish message to topic
  - Output: None

- **subscribe()**
  - Input: None
  - Process: Subscribe to topic
  - Output: Subscription status

#### Website
- **displayInfo()**
  - Input: Information
  - Process: Display information about the FollowBot
  - Output: information of FollowBot is displayed

- **interactWithFollowBot()**
  - Input: Interaction commands
  - Process: Execute interaction commands with the FollowBot
  - Output: interaction command is executed

#### WebsiteInteraction
- **backendToFrontend()**
  - Input: Backend data
  - Process: Transfer data to frontend
  - Output: None

- **controlRFollowBot()**
  - Input: Control commands
  - Process: Send control commands to FollowBot
  - Output: control command is executed

#### Mapping Process

1. **BC Mapping API**
    - **getOptimalPath()**
        - **Input**: `currentLocation`, `destination`
        - **Process**: Calculate the best possible path from `currentLocation` to `destination` using BC map data.
        - **Output**: Optimal path as a list of coordinates
    - **navigateToLocation()**
        - **Input**: `targetLocation`
        - **Process**: Navigate FollowBot to the target location based on the optimal path.
        - **Output**: Success or failure status

2. **Google Maps**
    - **getDirections()**
        - **Input**: `startPoint`, `endPoint`
        - **Process**: Retrieve directions from Google Maps for the specified route.
        - **Output**: Directions as a list of coordinates
    - **calculateRoute()**
        - **Input**: `startPoint`, `endPoint`
        - **Process**: Calculate the route from `startPoint` to `endPoint` using Google Maps.
        - **Output**: Calculated route as a list of coordinates

3. **Database**
    - **storeMap()**
        - **Input**: `mapData`
        - **Process**: Store campus maps in the database.
        - **Output**: Success or failure status
    - **retrieveMap()**
        - **Input**: `mapID`
        - **Process**: Retrieve the map for a given campus.
        - **Output**

<h2> 6. Human Interface Design </h2>

<h3> Mobile App: </h3>
As a user when it comes to both the mobile application, it will contain most of the major functionalities. For instance with the mobile app you will be able to see how much battery life is currently on the system, as well as how much weight, the current distance it is away from you, as well as the interior temperature. With the mobile app you will be able to as well interact with the device by controlling its movement if needed. You will be able to test given features with it. Look at the specs of the FollowBot, as well as look at the health of the FollowBot. Parts and services will also be shown of the application itself. The app will be able to as well send you notifications based on how much health is currently on the system, whether if the FollowBot ran into some issues, or is in need of assistance. You as a user will be able to use the app throughout many different mobile devices ranging from apple to android. 
<br><br>

#### Important Functionalities 
Visually on the top right corner of the screen will indicate the battery life of your FollowBot. The middle of the screen will consist of a 3d model version of the FollowBot, while beneath the FollowBot will indicate the amount of weight that is currently on the system. In the middle above the FollowBot will indicate the current temperature within the interior of the FollowBot. A small tab button on the bottom right corner will allow the user to see how far away the FollowBot is from the user. 
<br><br>

#### Settings
on the top left corner will be a setting icon for the FollowBot, where you will be able to find the specs of the FollowBot, changing capabilities for when you want to change the distance between you and the FollowBot, as well as the ability to switch on human control access towards the FollowBot. When switching on human access within the mobile app, the ui will change to a control panel where you will now be able to control the FollowBot through touch screen.

#### Authentication
When accessing the app it will first bring you to an authenticator screen, where you will need to input your username or password . If the user is signing in for the first time then they'll also need to input the FollowBots authentication key in order to access their specific FollowBot that they purchased, as well as their email. However once they do it the first time they won't need to do it again. As a user you will be able to change your password, or username if you forgot. In order to do so, an email will be sent to the user in which they will have to confirm or not that they want a change for a new username or password.

### Website: 
As for the website, it will have minor interactions with the user. But for the user, the website will offer another variety of options that is quite different compared to the mobile app. For instance, the web interface will consist of a variety of tabs to open and see. One tab will consist of a feedback page/guide where you as the user that is currently an owner of the device will be able to ask questions or discuss topics based on the robotic device that you have on hand. Questions can vary from hardware parts, to ways in keeping the FollowBot clean, updating its software, or even future changes in parts for the FollowBot. 
<br><br>

#### Relevant tabs for user to go about
Other tabs will consists of information of the FollowBot, as well as a video recording in how the FollowBot interacts with it's surroundings. Another tab will be accessible to owners of the FollowBot where they will be able to interact with their FollowBot and see how well it's able to avoid obstacles while being able to follow a coordinated path. You will be able to control the FollowBot with this minor interaction that will be found on the web page.
<br><br>

#### News Posting
Another important feature that we would like to add is a news posting tab,
where people will be able to get notified in future updates based on the FollowBots development progress, or even updates on future releases for the FollowBot itself, such as enhancements in parts or software.

#### Authentication
As mentioned within the Mobile App user interface, it will be the same. However the difference will be that you don't have to sign in immediately, The webpage is meant for informational purposes. If you wish to create an account or sign in. A user profile icon for that will be found above in the right hand corner of your screen.

#### Mapping
ON the Mobile app there will be a mapping interface where you will be able to obtain the location of the FollowBot and pinpoint it to a new location. Either to you or to a point of interest. It will give you the estimated time for it to travel there.

### 6.2 Screen Images

#### Mobile App:
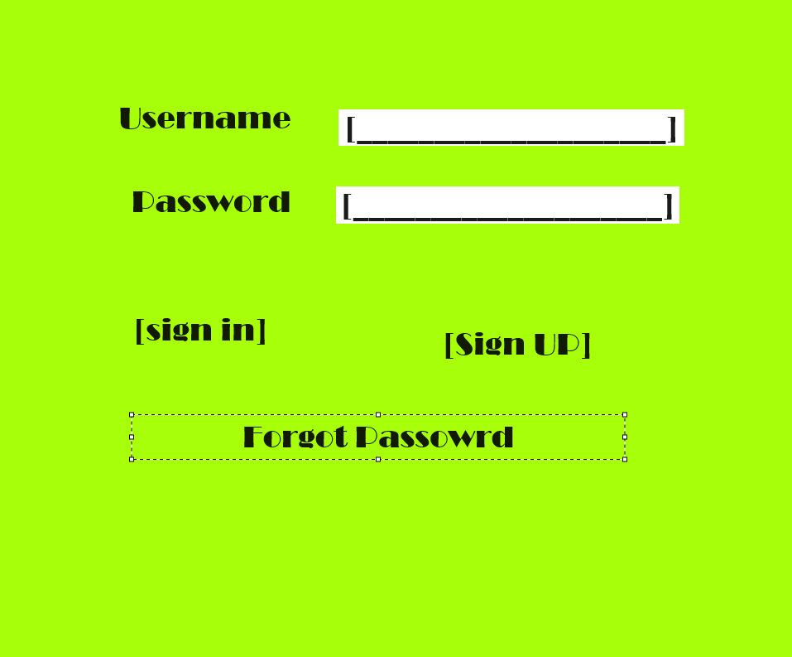
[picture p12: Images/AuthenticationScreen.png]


*Authentication Screen*

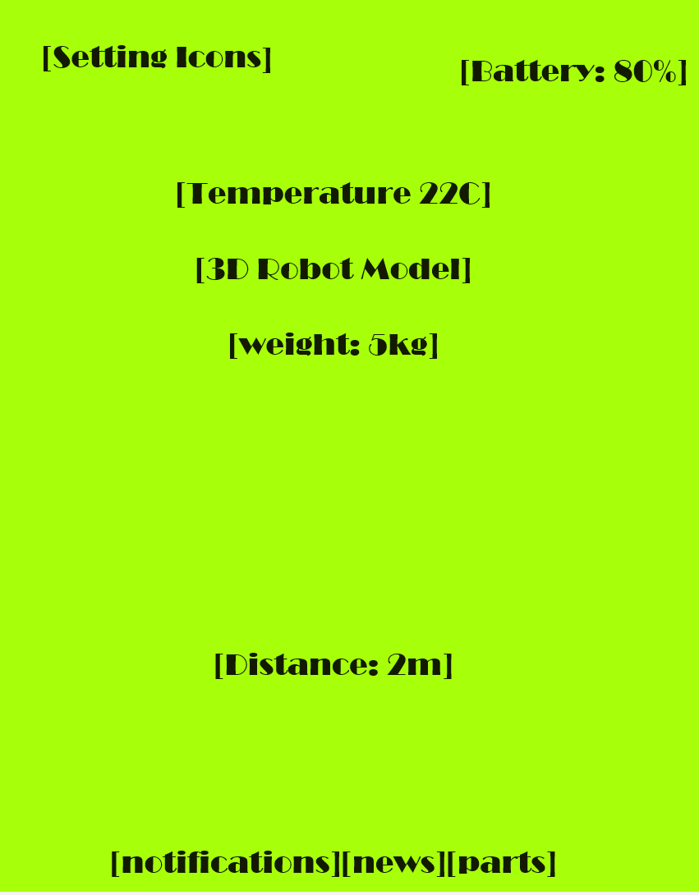
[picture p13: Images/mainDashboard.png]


*Main Dashboard*

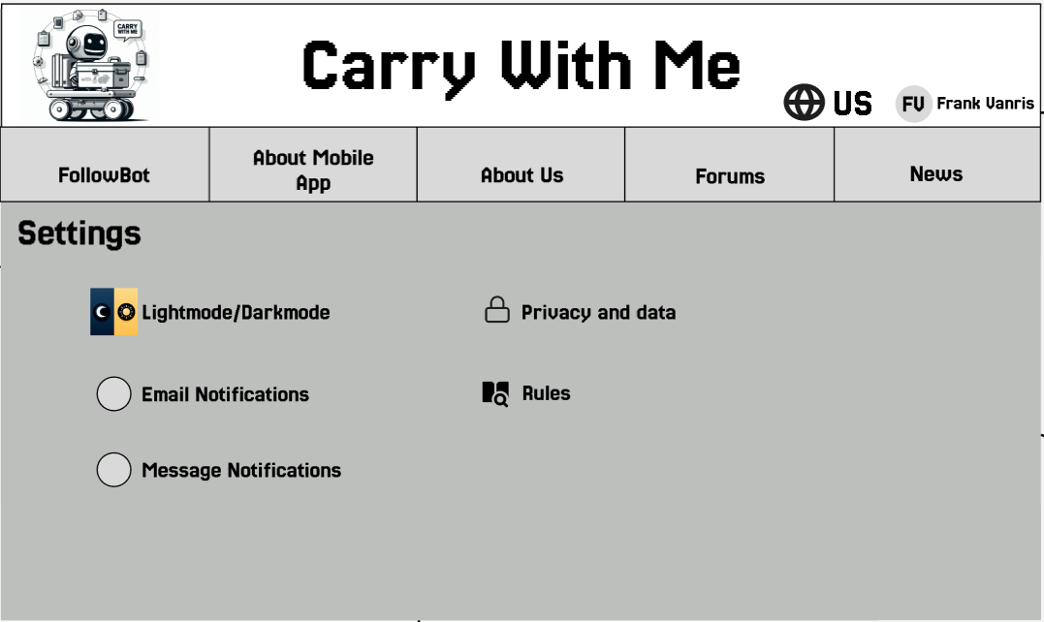
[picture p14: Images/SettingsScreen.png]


*Setting Screen*

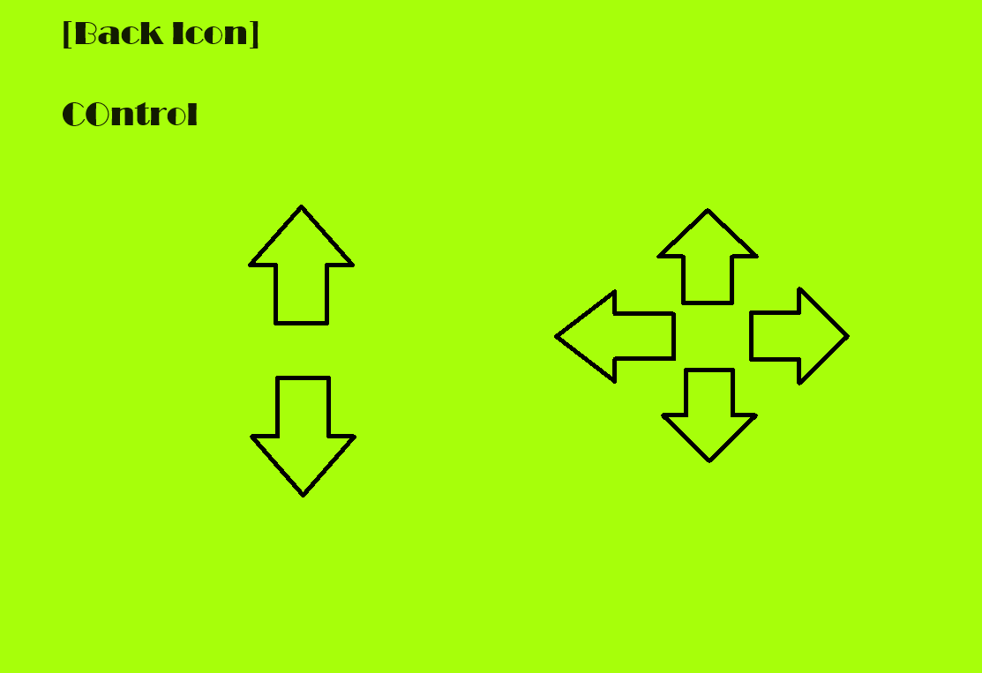
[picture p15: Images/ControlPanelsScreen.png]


*Control Panels Screen*

#### Website:

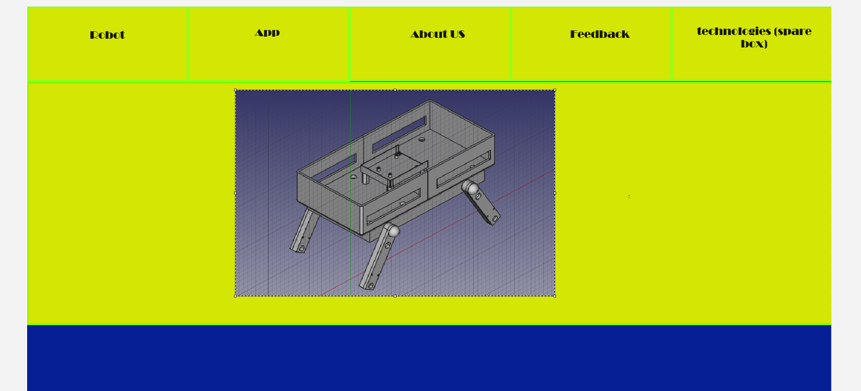
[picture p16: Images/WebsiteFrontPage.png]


*Front page of website*

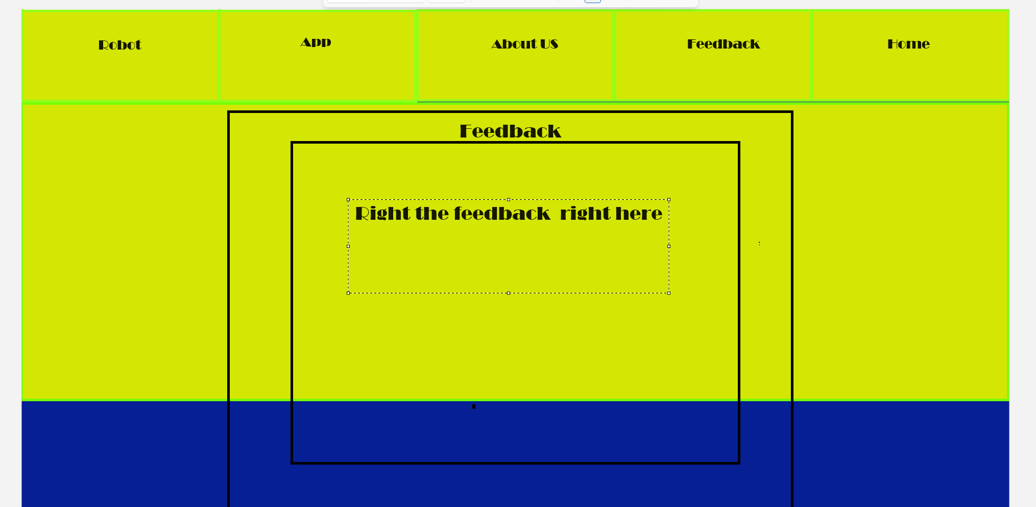
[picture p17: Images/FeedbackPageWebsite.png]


*Feedback page of website*

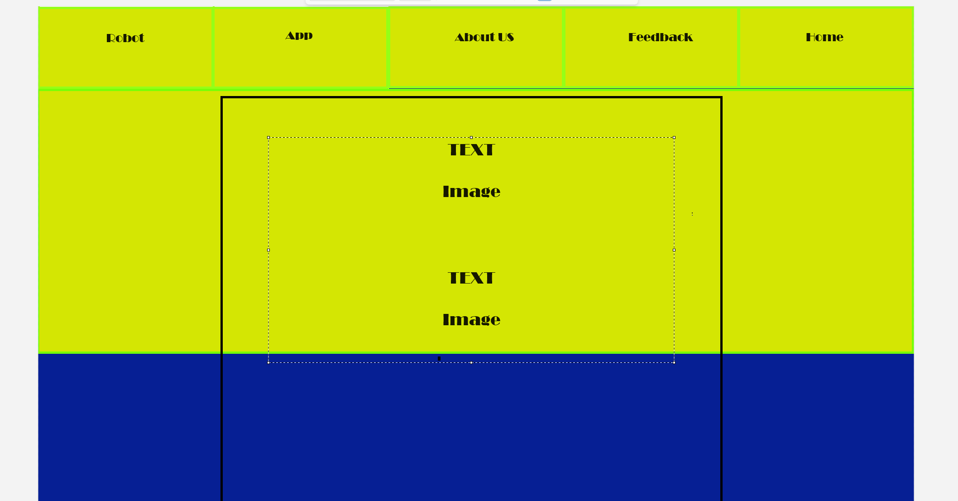
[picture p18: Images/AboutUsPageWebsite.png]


*About us page of website*

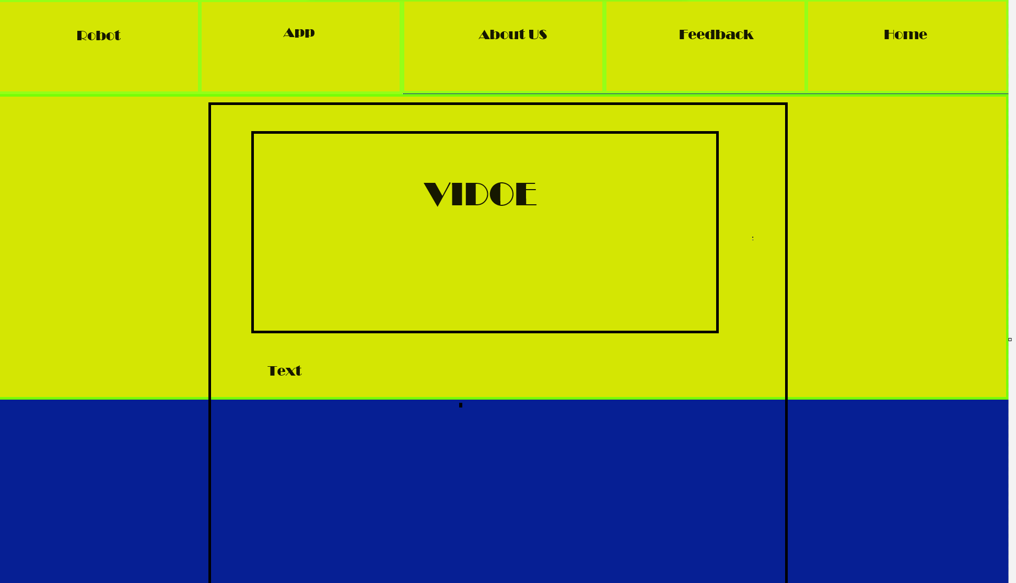
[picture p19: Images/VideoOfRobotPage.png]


*Video of FollowBot* 

<br>

### 7. Requirements Traceability Matrix

| Requirement-ID| Requirement Description| Design Component| Data Design Component| Interface Design Component|
|---|---|---|---|---|
| FR-001| User Authentication| AuthProcess| Database| Authentication|
| FR-002| Display Battery Life| MobileApp| Data| RealTimeDataRetrieval|
| FR-003| Display Weight Information| MobileApp| Data| RealTimeDataRetrieval| FR-004| Display Distance Information| MobileApp| Data| RealTimeDataRetrieval|
| FR-005| Display Temperature Information| MobileApp| Data| RealTimeDataRetrieval|
| FR-006| Control FollowBot Movement| MobileApp| MotorControllerNode| MotorDriverNode|
| FR-007| Send Notifications| MobileApp| Data| RealTimeDataRetrieval|
| FR-008| User Feedback and Guide| Website| Database| MailApplication|
| FR-009| Display FollowBot Information| Website| Data| RealTimeDataRetrieval|
| FR-010| Video Recording of FollowBot Interaction| Website| Data| RealTimeDataRetrieval|
| FR-011| FollowBot Interaction and Control| Website| MotorControllerNode| MotorDriverNode|
| FR-012| News Posting and Updates| Website| Database| MailApplication|
| FR-013| Generate and Validate FollowBot Authentication Key| RobotAuthKey| Database| Authentication|
| FR-014| Analyze Past Data for Movement Optimization| LearningModel| Data| RealTimeDataRetrieval|
| FR-015| Store and Retrieve User Data| Database| Database| Authentication|
| FR-016| Obtaining Location on Map| Map API| Data| Mapping|
| FR-017| Obtaining Time it takes from point A to B| Map API| Machine Learning| Mapping|
| FR-018| Obtaining User location for Mapping| Map API| Data| Mapping|

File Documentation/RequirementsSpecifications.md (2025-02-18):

<h1>Software Requirements Specifications<br>
for<br>
FollowBot</h1>

<h2> Version 1.0 approved<br>
<br>
Prepared by Frank Vanris, Igor Janotti, Trong Duong, Joseph Hoang<br><br>
Bellevue College<br><br>
Last Modified: 11/11/2024<br><br></h2>
<br><br>

# Table Of Contents
- [Introduction](#1-introduction)
- [Overall Description](#2-overall-description)
- [Specific Requirements](#3-specific-requirements)
- [Breakdown of work/Project timeline plan](#4-breakdown-of-workproject-timeline-plan)

<br><br>
# 1. Introduction <br><br>

**1.1 Problem statement**<br><br>
*To give the disabled access to a device that will map their location in order to follow and warn them of obstacles in the way. To provide individuals with a FollowBot that can carry their belongings, while weighing the benefits against the costs.*<br><br>

**1.2 Summary**<br><br>
*Designed to assist individuals in transporting their belongings across various environments, this FollowBot is particularly beneficial for those who face physical challenges. Despite its high-quality features, we’ve strived to keep the cost as affordable as possible, aligning it with our budget constraints.*<br><br>

**<h3>1.3 Product Scope</h3>**<br><br>
**1.3.1 In scope**<br>
* *The individual will be allowed to put up to 50 lbs of weight onto the FollowBot itself with no hassle whatsoever.*<br>
* *The FollowBot will recognize the registered user and follow them while carrying their belongings. .*<br>
* *Design and implement a machine learning object recognition model for classifications such as: stairs, signs, obstacles, people who are not the user.*<br>
* *Design a NoSQL database for the user to opt into uploading product data for continuous improvement of the model.*<br>
* *Develop AI capabilities for the FollowBot, such as voice recognition to allow for voice commands such as: “Go to…”, “Stop”.*<br>
* *Integrate mapping capabilities for the FollowBot to know nearby tags (viable paths, ramps, entrances) which the bot may auto-path to in the event of obstruction.*<br>
* *Develop a mapping interface for the user to direct the bot to a target location, so the FollowBot may be delivered or be a delivery service.*<br>
* *Develop a companion, multi-platform application for the user to access the mapping interface, FollowBot stats (battery life, temperature, weight), and live location.*<br>
* *A user may register themselves to the robot via access key and authorization protocol through the application.*<br>
* *The companion application will also provide additional sources of information, such as FAQs, user forums, and contacting a developer for questions or problems.*<br>
* *In the event that the FollowBot cannot self-correct or navigate beyond an obstacle, the user will be notified and allowed manual control of the bot through the application.*<br>
* *Developing a complex security system for the FollowBot, such as encryption or two-factor authorization.*<br>
* *The mobile app should be cross-platform between all mobile devices*.<br>
* *will contain a mobile user interface for the individual to use in order to control/look at the specs and health of the FollowBot.*<br>
* *Battery life for the FollowBot should be above 8 hours of life and the device must be rechargeable.*<br>
* *Building a system for the FollowBot to recognize and respond to specific individuals.*<br>
* *Allow for historical data retrieval based on the battery life, autonomous movement of the FollowBot, as well as distance control in order to find better ways for autonomous movement through machine learning models.*<br>
* *Developing advanced AI capabilities for the FollowBot, such as voice recognition or autonomous decision-making.*<br>
* *Cost of product must be at most under \$500 and at best under \$300.*<br><br>

**1.3.2 Out of scope**<br>
* *Creating a solar-powered charging system for the FollowBot.*<br>
* *Implementing a system for the FollowBot to handle fragile items or sort belongings into specific categories.*
* *The ability for FollowBot to go upstairs, and go through doors and tedious environments.*
<br><br>

**<h3>1.4 References</h3>**<br>
Here are the given links to certain documents and websites that will guide us for making the hardware & software:<br><br>
links:<br><br>
**Hardware**:<br>
* https://forum.arduino.cc/t/Followbot-following-one-specific-human/182826/6 (FollowBot following questionnaire)
* https://shorturl.at/YFixs (L293D Motor driver datasheet)
* https://5.imimg.com/data5/PX/UK/MY-1833510/l293d-based-arduino-motor-shield.pdf (L293D based motor shield)
* https://www.wevolver.com/article/sensors-in-robotics (sensory intel)
* https://en.wikipedia.org/wiki/Lidar (Lidar sensors)
* https://shorturl.at/MdsLB (How to choose the right battery for your robotics system?)
* https://www.wiferion.com/us/wireless-charging-for-robots/#:~:text=Inductive%20Charging%3A%20This%20is%20the,receiver%20coil%20in%20the%20robot (Induction charging)
* https://www.sparkfun.com/datasheets/GPS/Modules/LS20030~3_datasheet_v1.2.pdf (GPS module Datasheet)
* https://www.amazon.com/HiLetgo-MPU-6050-Accelerometer-Gyroscope-Converter/dp/B01DK83ZYQ/?th=1 (Gyroscope)
* https://www.amazon.com/Arducam-Raspberry-Motorized-Software-Precise/dp/B09VSVB4DT/?th=1 (Camera)
* https://www.amazon.com/GeeekPi-NVMe-Adapter-Raspberry-Support/dp/B0CRK4YB4C/ (NVMe drive)
* https://www.amazon.com/Encoder-Gearmotor-300RPM-Arduino-Printers/dp/B07GNGCNK1/ (Motors with Encoders)

**Software**: <br>
* https://docs.ros.org/en/foxy/index.html (ROS2)
* https://docs.arduino.cc/ (Arduino Docs)
* https://www.instructables.com/Building-a-Mobile-App-to-Control-Arduino-Board-Via/ (Mobile application interface with hardware)
* https://docs.ultralytics.com/guides/raspberry-pi/ (“You Only Look Once” ML model documentation)
* https://pmc.ncbi.nlm.nih.gov/articles/PMC7436166/ (SRRI)
* https://onlinelibrary.wiley.com/doi/10.1155/2022/8274455 (WiFi Triangulation)
* https://pmc.ncbi.nlm.nih.gov/articles/PMC7436166/ (RSSI for WiFi positioning)
* https://www.swri.org/industry/industrial-robotics-automation/blog/web-based-Followbot-user-interface (webpage interface between robotics)
* https://www.jetbrains.com/help/kotlin-multiplatform-dev/cross-platform-frameworks.html (cross-platform frameworks)
* https://tinyurl.com/3stbh3s6 (Security & Authentications)
* https://daylightstrategy.com/ga4service/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 (Google Analytics services)

# 2. Overall Description <br>
**2.1 Compete analysis**<br>

| Top Competitor | Strengths | Weaknesses | Opportunities | Threats |
| --- | --- |--- |--- |--- |
| Gita(mini) & Gita(plus) | - both devices based on the type can carry up to 20-40 lbs <br> <br> - can follow the user and holder of the device while avoiding obstacles along the way <br> <br> - Contains an array-set of sensors in order to track its leader and avoid obstacles along the way <br><br> - contains a bluetooth speaker that is used for music| - primary focus is to carry your groceries<br><br> - battery life can only hold up for 4 hours at most <br><br> - the price range for such a device is above $1000 | - Creating a product that will be able to carry more weight compared to the counterparts. <br> <br> - improve the battery life to withstand as much as 8 hours or more <br><br> - improve the costs for such a Followbot so that is affordable for any consumer <br><br> - Adding Mapping capabilities so that the Followbot can do more <br><br> - The device will be able to follow its own path without the user in mind <br><br> - Adding security capabilities to prevent other users with interfering with the device | - improvement and increase of weight lifting for a device similar to what we plan to create <br><br> - The costs for a Followbot from a competitor decreases to a consumer level friendly product |

**2.2 User Classes and Customer Profile**<br>
* The who for our user classes include Students, Elderly, Families, Workers, the Disabled, and Individuals <br>
* The when for all of our users would be when they need to travel by foot with belongings that they do not wish to carry. <br>
* The how would be that the FollowBot would be allowed to travel to a specific location or have the FollowBot recognize the user either by connection or shape in order for it to follow them. <br>
* Frequency will be based on how far the FollowBot will need to travel to a given location with a user or by a task from a user <br><br>

**Intended Users:**
**Intended Users:**

| Who | What | Where | Why | When | How |
|---|---|---|---|---|---|
| Business Campuses | The FollowBot will map out the campus to be equipped with surrounding tags and to go to specific locations. | The Campus | To allow for transportation of items between designated locations to reduce weight load on workers or students. | Whenever the device is needed. | The mapping interface will allow users to send the bot to a given location. The map will be based on the campus for easy navigation by the FollowBot. |
| The Disabled | The FollowBot can carry personal or work-related belongings for individuals with disabilities. | Any location needed by the disabled individual. | To assist disabled individuals in carrying belongings, relieving such concerns. | Anytime, such as going to the store, walking downtown, etc. | Disabled individuals can place belongings into the FollowBot and rely on its computer vision follow mechanics and a provided application. |
| Elderly | The FollowBot can carry belongings for elderly individuals, especially heavy or inconvenient items. | Residential areas, marketplaces, etc. | To assist elderly individuals in carrying heavy items during daily activities. | Whenever needed. | Elderly individuals can place belongings into the FollowBot, using its computer vision follow mechanics and the application. |
| Students | The FollowBot is designed to carry belongings such as books, notebooks, and computers. | Schools ranging from elementary to university | To alleviate the burden of carrying textbooks between classes or storing them in lockers. | During school hours or while moving around. | Students can place belongings into the FollowBot and rely on its follow mechanics and the application. |
| Families | The FollowBot can carry belongings including food, drinks, toys, medical items, and heavy loads. | Residential areas, open spaces, etc. | To help family members avoid carrying heavy items by hand during outings. | When traveling to recreational spaces, etc. | Families can place belongings into the FollowBot and rely on its follow mechanics and the application. |
| Workers | The FollowBot can carry personal or necessary equipment for workers. | Workplaces | To assist workers in carrying personal or work-related belongings that are heavy or inconvenient. | When needed to bring belongings to work. | Workers can place belongings into the FollowBot and rely on its follow mechanics and the application. |
| Individuals | The FollowBot can carry personal or work-related belongings for any individual. | Any location needed by the individual | To provide individuals a way to transport belongings due to weight or preference. | Anytime, e.g., shopping or walking downtown. | Individuals can place belongings into the FollowBot and rely on its follow mechanics and the application. |

**In Reality:**<br>
This device will give more accessibility to users that need assistance when carrying their belongings. This FollowBot is versatile and can be used by any individual, regardless of their current activity. Whether it's for work-related tasks, family outings, or simply to carry personal belongings, this FollowBot is designed to meet the individual's needs. <br><br>

**2.3 Design and Implementation Constraints**<br>

The construction of the FollowBot presents a significant challenge, given the intricate engineering required to create a device capable of carrying and autonomously following a user. The hardware components and their assembly will demand meticulous attention and precision.

On the software side we are utilizing the Arduino Uno Rev4 with PlatformIO for managing motor sensors. Meanwhile, we are leveraging the Raspberry Pi with the Robot Operating System (ROS2) for efficient logical processing, communication, and data flow.  We will be developing a companion application for the user to access aforementioned features and further documentation.. Mapping capabilities and path-finding algorithms will be applied to the FollowBot in order to avoid obstacles while following a designated path to a specific location. Computer vision techniques will be used to allow the FollowBot to follow the user if needed in order for it to carry their belongings. Modules for WiFi and GPS will come with software to improve general motion, enhance mapping, and the machine learning model.

In terms of project success, our primary focus will be on systematic organization (front-end, back-end, robotics) and incremental prototyping with progressive refinement. Our goal is to deliver a practical and beneficial product for any consumer seeking a FollowBot to carry their belongings or allow the FollowBot to go to designated places.

**2.4 Assumptions and Dependencies**<br>

The successful completion of this project hinges on several factors. A significant challenge could arise from changes in the hardware and software resources required for the FollowBot’s optimal functionality. However, these potential issues are secondary to the primary challenge of maintaining the product’s price under $500. This price point will be a constant consideration throughout the development of our product, but our determination and strategic planning aim to achieve or come close to this goal.

Potential changes in hardware and software could cause temporary delays in the product’s development. The procurement of necessary materials for the hardware aspect of the project could affect our timeline. Similarly, on the software side, the development of the application and machine learning models may encounter delays due to software requirements, errors, and bugs. However, based on our past experiences, we are confident in our team’s ability to address these issues promptly and meet our project deadline.

We plan to use reliable hardware that has proven effective in both major manufacturing environments and hobbyist builds. For the software, we will develop an API to establish a client-server model between the FollowBot and the application interface. . This will allow users to visually monitor the FollowBot’s activities, performance, and control the device based on user input.

To support the machine learning model and enable seamless data flow between the FollowBot, its application interface, and storage solutions, we will utilize Amazon Web Services (AWS) and DynamoDB. Leveraging AWS as our primary cloud infrastructure will enable reliable and scalable resources for data processing, model training, and storage. This will allow better ability to manage and update the machine learning model while relieving some stress to the physical bot. DynamoDB will be used to store the data collected by the FollowBot, including user credentials, historical data, and any image data required for model training. DynamoDB flexibility in adjusting data structures will offer an ideal solution to handling structured and unstructured data. We will also be using Django API Library to establish a flow between these two systems.  

# 3. Specific Requirements <br>

**<h2>3.1 User Interfaces</h2>**<br>

<h3> Website UI </h3>

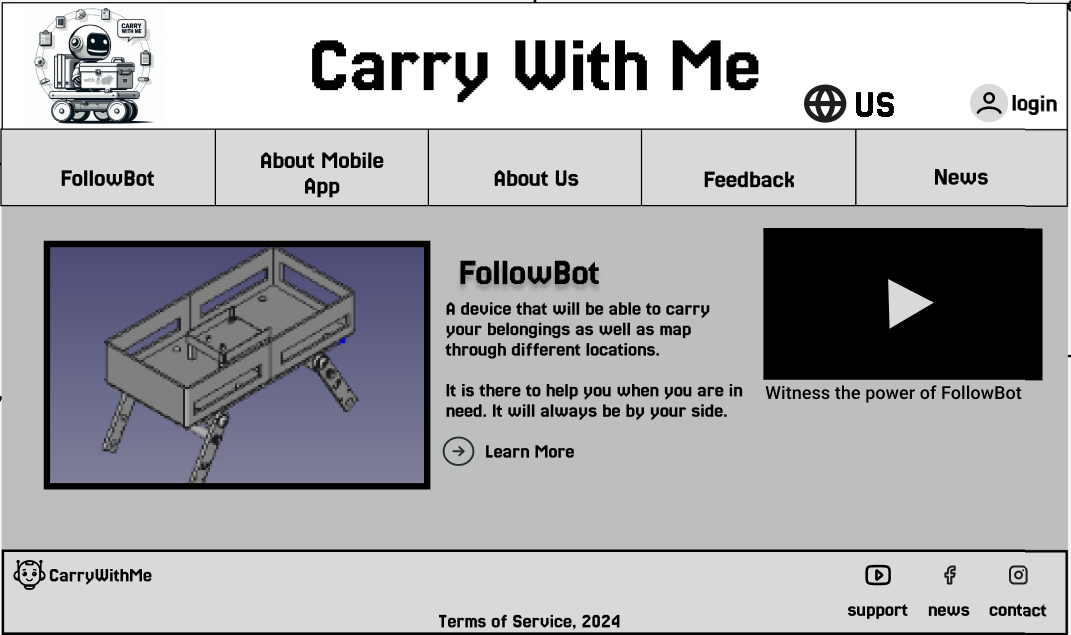
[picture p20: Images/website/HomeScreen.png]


***Home Screen of website***
* On the homepage of the website, users will find a series of tabs that provide insightful information about FollowBot, its mobile app, and the developers behind it. These tabs allow users to easily navigate and learn more about the project's various aspects.

<br>

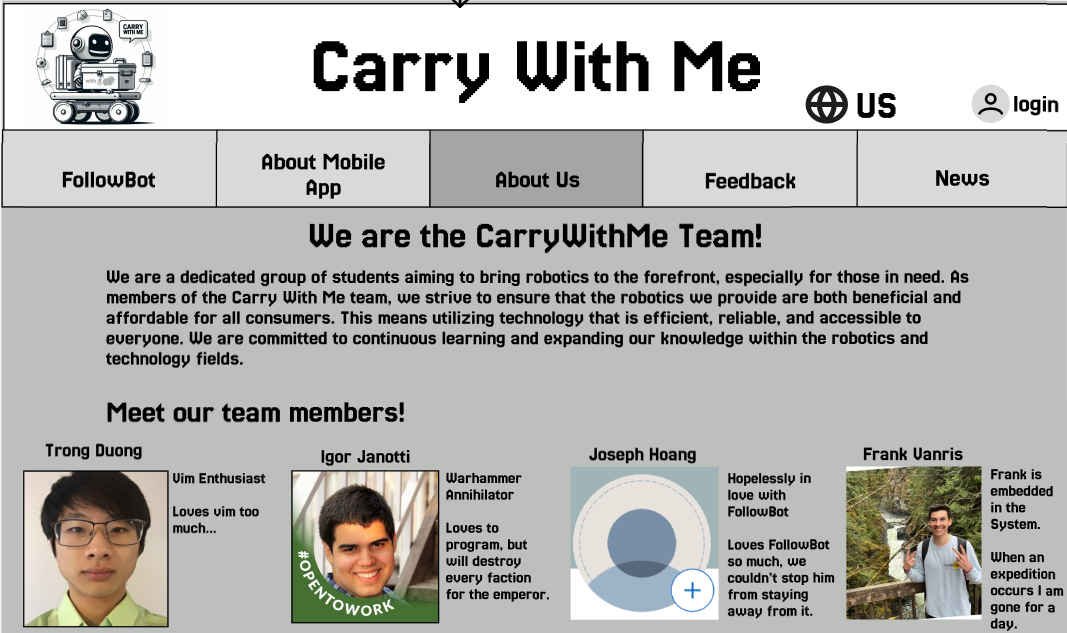
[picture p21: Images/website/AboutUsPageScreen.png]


***About us page which will contain a bio and photos of the developers***
* One of the tabs will provide detailed information about all the developers who worked on this project. You can scroll from top to bottom to learn about the entire development process of FollowBot.

<br>

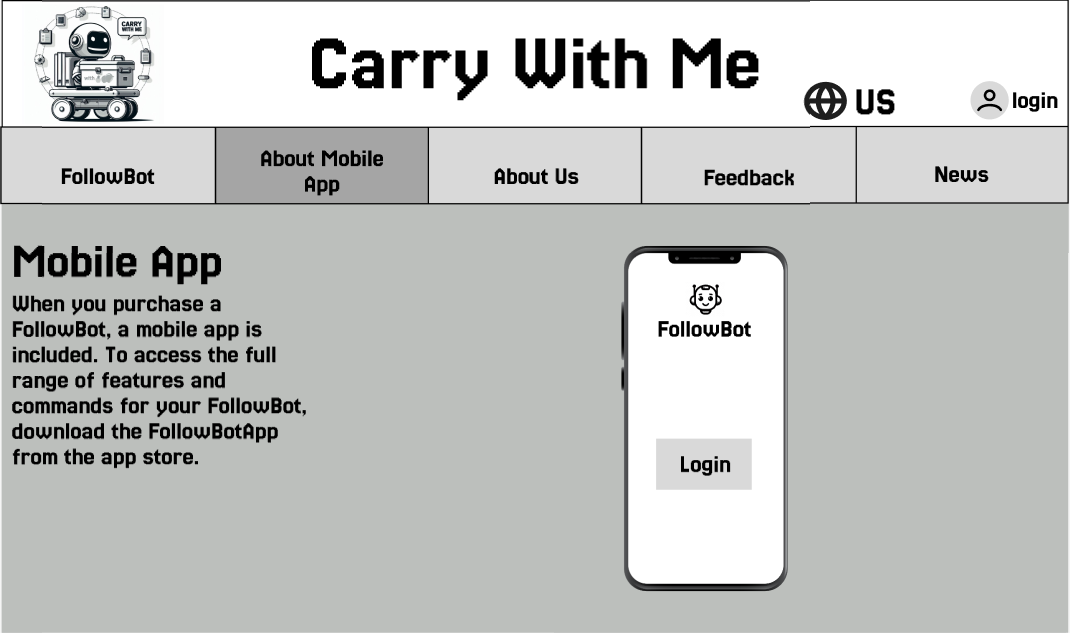
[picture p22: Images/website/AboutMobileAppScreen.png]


***The About Mobile App page explains how the mobile app interacts with FollowBot***
* A Tab that contains insightful information about the mobile app
<br>

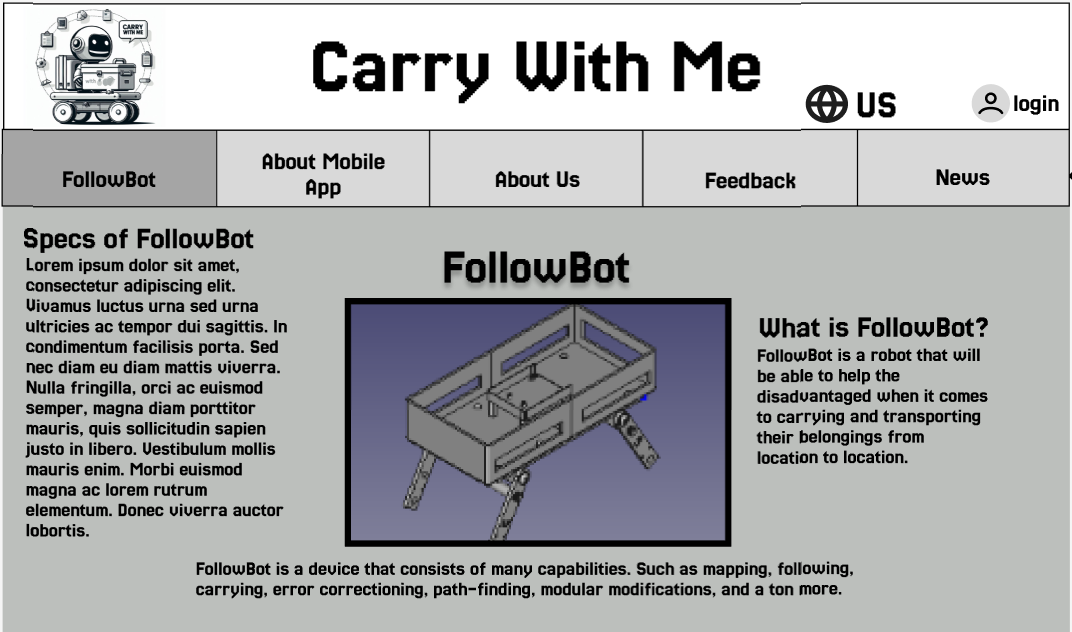
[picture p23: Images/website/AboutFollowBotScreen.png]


***The About FollowBot page***
* It contains information on everything about FollowBot such as its specs, and its purpose.
<br>

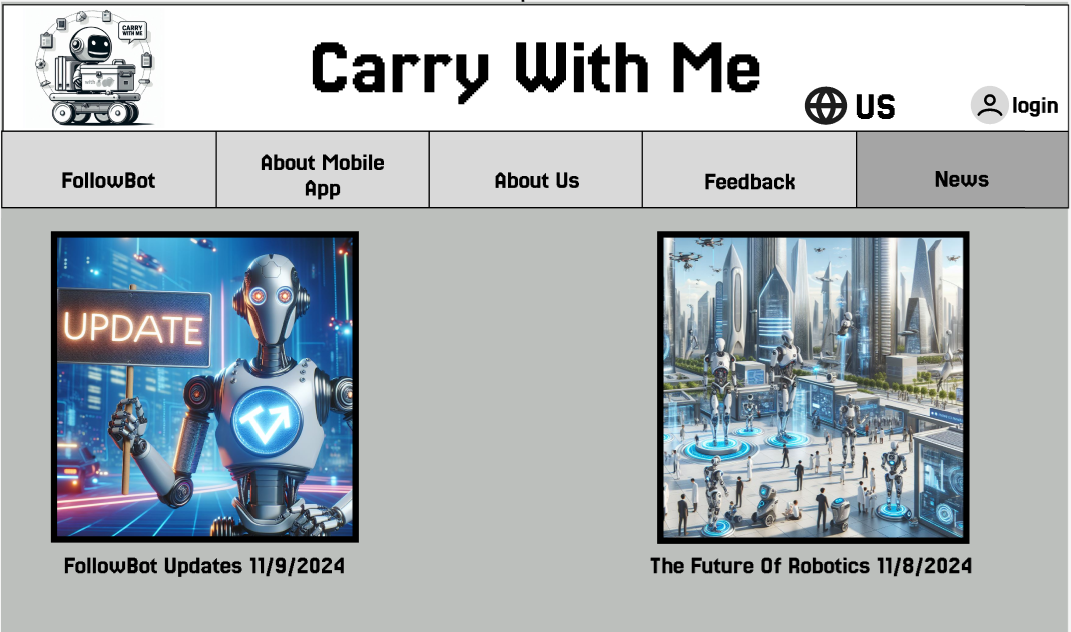
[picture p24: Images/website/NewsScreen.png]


***The News page***
* It will contain updates in what the team has been working on 
<br>

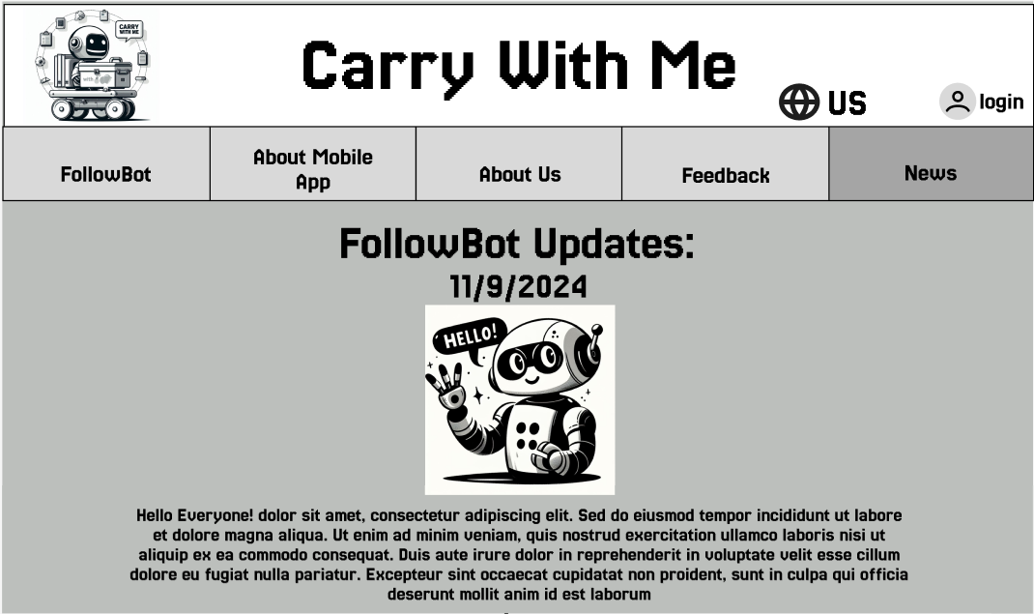
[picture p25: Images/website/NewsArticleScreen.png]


***News Article page***
* When clicking on a news article you will be brought to another page where you can read the news.
<br>

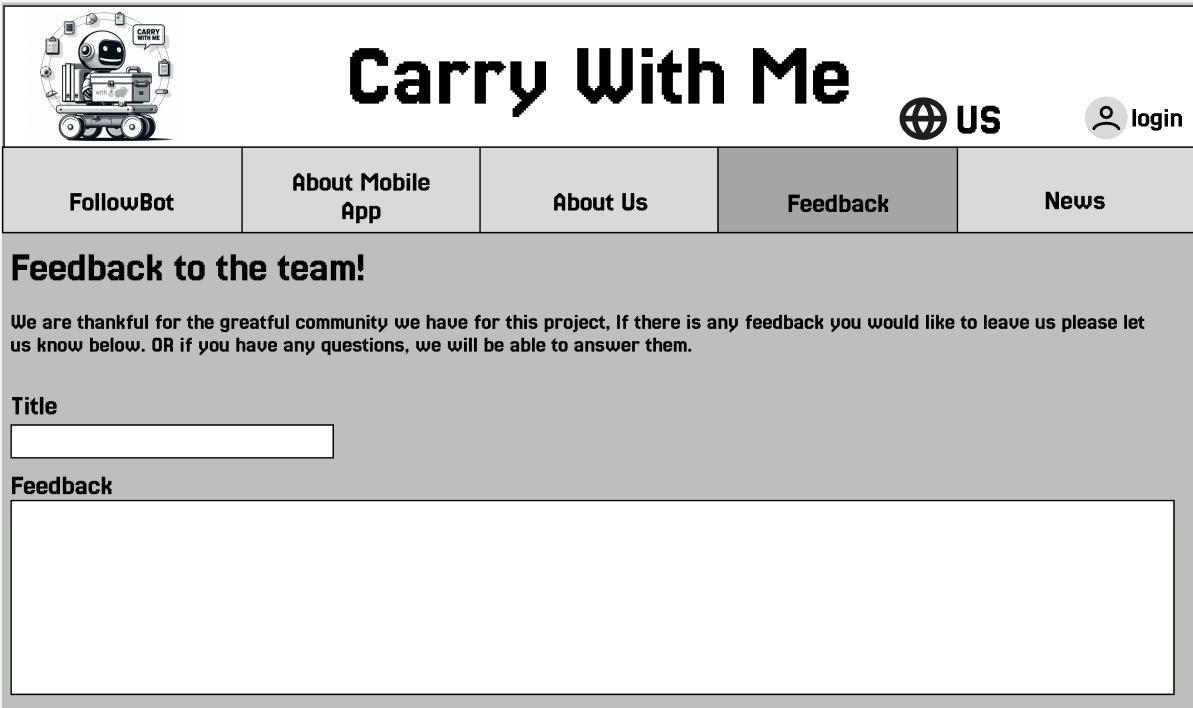
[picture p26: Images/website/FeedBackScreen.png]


***Feedback page***
* When you click on the Feedback page there will be a area where you can send feedback to the team of FollowBot. You can as well ask questions if needed.
<br>

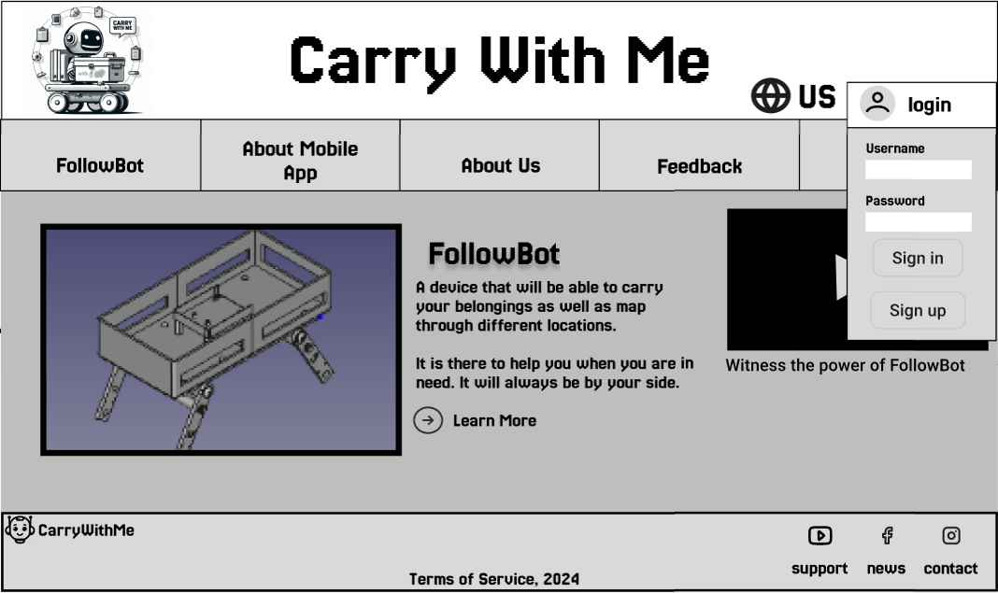
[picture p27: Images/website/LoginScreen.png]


***Login screen***
* When clicking the login button you will be met with a slide in screen where you will need to input your username and password.
* If you do not have an account you will be able to sign up.
<br>

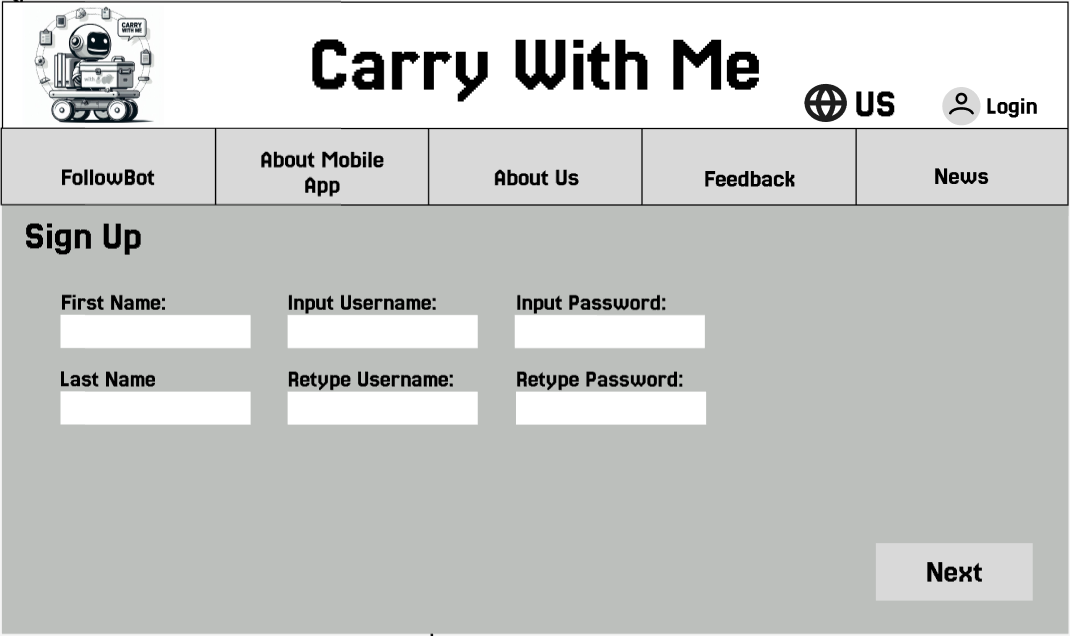
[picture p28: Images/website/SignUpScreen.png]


***Sign Up page***
* When you click on the signup option you'll be met with another page where you'll need to input your first/last name, your username, and your password.
* Once you do that you'll need to click next.
<br>

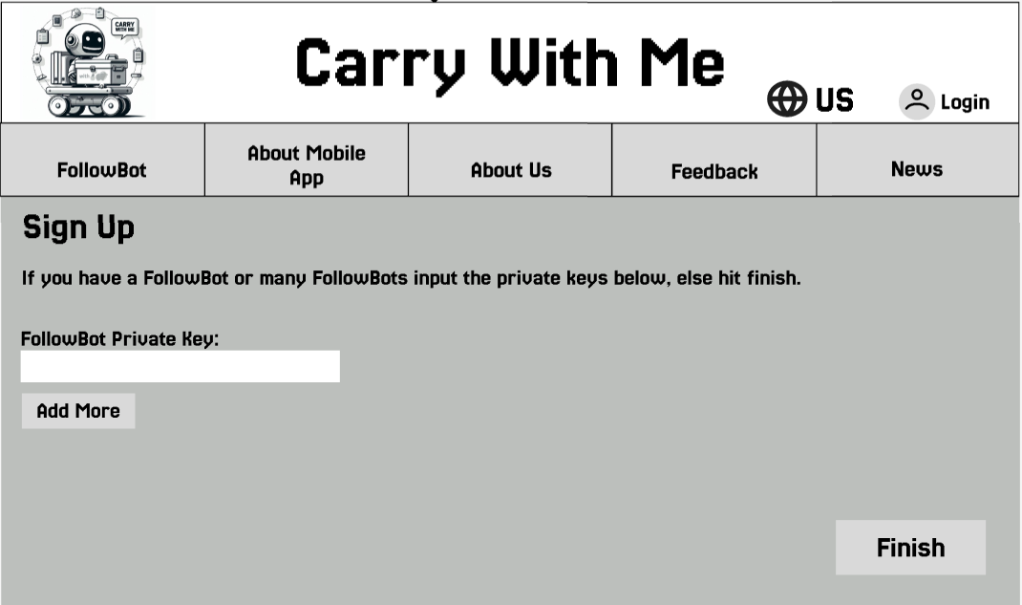
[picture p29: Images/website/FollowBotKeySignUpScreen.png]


***Sign Up Private Key Page***
* When you click next you will be met with another page to input your FollowBots Private Key if you have one. If you do not have one you can click Finish and you will have your account set up without any FollowBot on your account.
* If you have more than one FollowBot you can input as many private keys as you like.
<br>

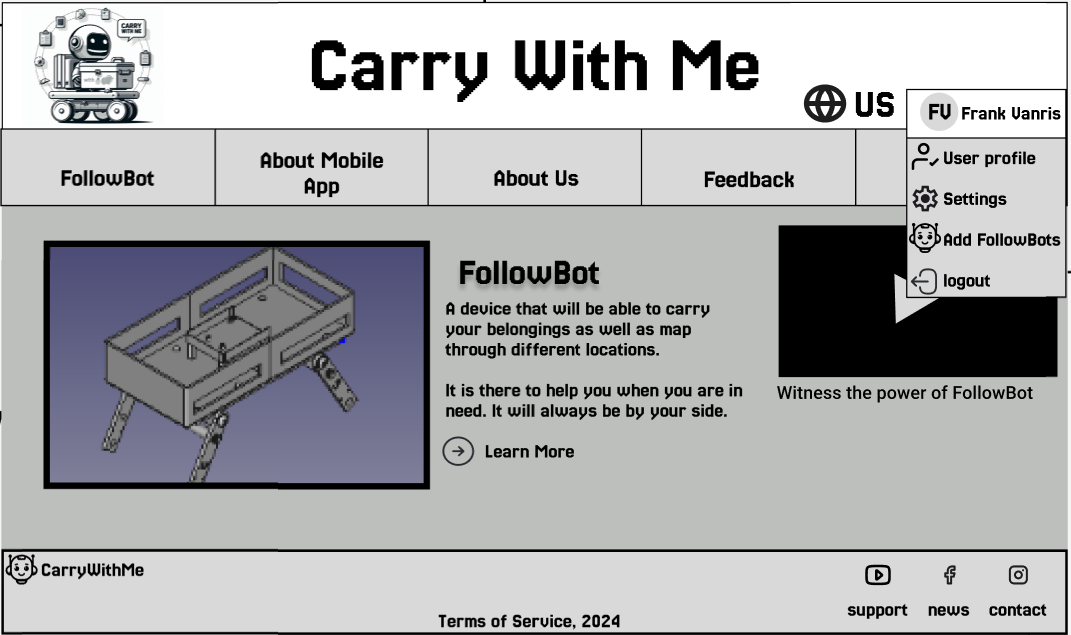
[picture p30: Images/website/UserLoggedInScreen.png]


***Logged In Screen***
* When you are logged in you will be brought back to the homepage where you will see that you are signed in.
* When clicking your name you will be met with a drop-down bar of certain mini tabs that you can click on ranging from your posts to you logging out.
<br>



***User Profile Page***
* When clicking on the User profile Icon, you will be brought to your user profile where you can check your everything that is related to your FollowBot (If you have one).
<br>



***Analytics Page***
* When you click on the analytics button, you will be met with everything analytics wise to your FollowBot.
<br>



***Controls Page***
* When you click on the Robotic Controls button, you will be met with a screen where you can Control your FollowBot if you are connected to it, as well as receive a live feed of what the FollowBot is visually seeing.
<br>



***Mapping Page***
* When you click on the Mapping button, you will be met with a screen of the Bellevue College campus. The Mapping System will locate FollowBot and See if it is directly in BC. If it is you will be allowed to map your FollowBot to any specific location on BC if safe to do so.
<br>



***My Account page***
* When you click on the my account screen you will be met with a list of buttons you can click from, as well as see the FollowBots that are accessable through your account.
<br>



***Signal page***
* When you have FollowBot Around, you will be able to check the signal to see if you are connected to any of your FollowBots. 
* Developer: (For testing purposes) we will print out the private key just to see it's able to retrieve that information. Will be applicable and useful to see if we can have multiple FollowBots interact with one another without any interference
<br>



***Live Feed page***
* The Live Feed page will allow the user to see visually what FollowBot is seeing when going to a specific location.
<br>



***Settings page***
* This page will include your basic commands to change the look of your environment as well as prevent or allow notifications to your phone or email. Along with it you will be able to Delete your Data or export it into a csv.
* Rules will also be mentioned where you can read up on what you can and can't do with FollowBot.
<br>



***Darkmode screen***
* When you click the lightmode/darkmode icon in settings you will be able to change the color format of the website. 
<br>



***Privacy & Data page***
* When clicking the privacy & data icon you will be met with another page where you can either delete all of your data OR export your data into a csv.
<br>



***Rules page***
* When you click on the rules button you'll be met with the rules page where you'll read everything that you can and can't do with FollowBot.
<br>



***Add FollowBot Page***
* When you click on the Add FollowBot Icon, you will be met with another page where you can add one or more FollowBots into your account.
* We will be adding an Admin feature later on which will prevent a user from adding more FollowBots unless they are a admin.
<br>

<h3> WebApp </h3>


***Webpage but on mobile***
* When opening up the webpage on the phone, everything will be formatted to fit the screen. The login process will stay the same.
* The sign up process although not depicted will also stay the same.
<br>



***Webapp tabs on mobile***
* When you click on each tab, you will see all the relevant information specific to that tab.
* Stating again, each of the tabs and information has been reformatted to fit on the mobile device.
<br>



***Settings functionality of web on mobile***
* The settings functionality is replicated on mobile. And as shown it is made to fit the screen.
<br>



***User Profile***
* When you login, you will be able to get on your user profiler and use all of the given functionalities that it offers.



***More from the User Profile***



***Again more from the User Profile***
<br>



***Adding FollowBots on mobile***

* As a user you will be able to add more FollowBots through your account via this screen.
* Again it is made to fit your mobile device.
<br><br>

<h3> Mobile App UI </h3>



***Landing page for the mobile app***
* The mobile app is intended for users that own or have been assigned a FollowBot. When using the app for the first time, the user will be prompted to register an account alongside an access key. Otherwise, the user may log in and have access to subsequent features.



***Features that are accessible with a registered FollowBot***
* Once logged in, the user will be met with this dashboard (1).
* The mobile app will display the bot's battery life and distance from the device.
* (2) a mobile mapping interface, allowing for track their bot in real time and directing it to a registered location.
* (3) manual motor control
* (4) news about the FollowBot, including software updates and scheduled maintenance.
* (5) notifications pertaining to their bot such as activity and status.


***User settings***
* clicking the settings button on the feature dashboard will bring you to this page (6).
* (7) privacy & data: information about our data collection done by the FollowBot with the available option of opting out.
* (8) guideline of rules: what you can and can (should) not do with the FollowBot. 

<h3> Robotic UI Interface </h3>



***Login Screen, Connection Successful Screen & Connection Unsuccessful Screen***
* When it comes to connecting to a network, the robotic interface on the standalone device will allow us to input our ssid and password for a network.
* If the connection is successful you will be met with a friendly screen saying you are connected. You will be allowed to be go back to the login page if you wish.
* If the connection isn't successful you will be met with a sad screen saying that you could not connect to the Network. You will be able to direct back to the login page so you can try again.

**Business Capabilities**

Businesses will be able to register as an admin for their corporation, enabling them to control multiple FollowBots. As an admin, additional authentication will be required. The (yes & no) placeholder is for us to discuss and finalize the authentication design for admins.

As an admin, you will have the ability to share your FollowBot with other users or students in need for a limited period. HOWEVER, due to the increased server usage for retrieving data from multiple FollowBots, admins will need to sign up for a monthly subscription to use our services when managing multiple FollowBots.

**3.2 Functional Requirements**<br>
* The user will be able to place their belongings within the FollowBot without affecting the further functionalities.
* Mapping mechanics for the FollowBot to go to specific locations around the bot’s designated campus.
* Computer vision mechanics and learning models in order for the FollowBot to identify the registered user when following.
* The FollowBot that will follow the user while avoiding obstacles.
* The FollowBot will respond appropriately to user voice commands, and ultimately be able to self-handle unique instances.
* At the same time the user will be able to control certain mechanics of the FollowBot within the application.
* The application needs to send notifications to the user about the FollowBots needs, as well as possible issues.
* Historical data may be stored and retrieved to continuously improve the machine learning model and optimize functionalities such as autonomous movement and battery life.
* The user will be able to opt out of data collection, so that paths and images taken will remain local and not be uploaded to the collective database.
* And as a consumer that wishes to purchase the product, they will be able to visit the website that contains information about our product. And purchase our product from the site. <br>

**3.3 Performance and Software Quality Requirements**<br>

1. **Reliability**: The FollowBot should operate without failure under specified conditions for a designated period of time. It should be able to recover from potential failures without significant downtime.<br><br>
2. **Efficiency**: The FollowBot should make optimal use of system resources such as memory, disk space, and processing power. The mobile app and website should load quickly and respond to user input without delay.<br><br>
3. **Usability**: The FollowBot, mobile app, and website should be user-friendly and intuitive. Users should be able to understand and use the system without extensive training or technical knowledge.<br><br>
4. **Maintainability**: The software should be designed in a way that allows for easy updates and modifications. The code should be well-documented and follow best practices for readability and maintainability.<br><br>
5. **Machine Learning**: Creating a learning model to identify specific objects for object avoidance and path-finding.<br><br>
6. **Mapping**: Using mapping APIs or BC map for pathfinding with FollowBot in order for it to go from location to location.<br><br>
7. **Portability**: The mobile app should be compatible with various operating systems (iOS, Android) and the website should be accessible from different browsers (Chrome, Firefox, Safari, Edge).<br><br>
8. **Scalability**: The system should be able to handle an increasing number of tasks effectively. It should be designed to scale up or down based on demand.<br><br>
9. **Security**: The system should protect against unauthorized access and data breaches. User data should be encrypted and the system should comply with relevant privacy regulations.<br><br>
10. **Interoperability**: The FollowBot should be able to interact effectively with other systems or devices. It should follow standard protocols for communication and data exchange.<br><br>
11. **Battery Life**: The FollowBot should be able to operate for a reasonable amount of time on a single charge. Power management features should be implemented to extend battery life.<br><br>
12. **Load Capacity**: The FollowBot should be able to carry up to 50 lbs of weight without impacting its performance or stability.<br><br>

**3.4 Data Requirements:**

* we will communicate between modules through buffers: `char[]`

* we will communicate to applications using file types: `JSON`

* `uint8_t` will be used for simple integer returns and encoding

* We will implement a data structure, such as a `HashTable` and dataframes, for ease of retrieval of client data from our database

* our bot will capture photos to be processed by our machine learning model:  photo format i.e. `JPEG`, `PNG`

# 4. Breakdown of work/Project timeline plan <br>

<br>

| Requirements | Quarters | Assigned to: |
|---| --- | --- |
| Req. 1: General Documentation for the product and prototyping FollowBot initial chassis. | Q1 | Frank, Igor, Trong, Joseph|
| Req. 2: Revising and polishing general documentation, developing the website, modifying the prototype with initial following mechanics for testing purposes, and beginning minor development on the mobile app. | Q2 | Frank, Igor, Trong, Joseph | 
| Req. 3: Polishing and refining FollowBot and the website, continuing development of the mobile app.Developing and evaluating machine learning models for pathfinding capabilities and object detection. Developing ability for the FollowBot to recognize simple voice commands. Developing the mapping system. Reiterating the application to include new functionalities. | Q3  |  Frank, Igor, Trong, Joseph  | 
| Req. 4: Refining the website and mobile app, strengthening security capabilities, maintaining functionality and improving following, voice recognition, and mapping mechanics. | Q4  | Frank, Igor, Trong, Joseph |
| Future: Reiterate on the website and mobile app for better user experience, and research innovative ways to integrate OpenAI technology into all FollowBot devices. Integrate inverse kinematics for the bot to handle slopes, stairs. | Q5 | Frank, Igor, Trong, Joseph |

<h3> Complete timeline: </h3>





| Essential-Backlog User Stories | Milestone | Assigned to: |
| --- | --- | --- |
| A user will be able to click tabs on the website to seek information about the FollowBot, how it performs, and how it works. | M1 | Igor |
| The user can register a personal account and link it to their FollowBot. | M2 | Igor |
| The user can connect their FollowBot via the website to test its functionality for testing purposes. | M3 | … |
| The user can register and log in to connect their bot to the network via a supplemental screen module on the physical bot. | M4 | Frank |
| The FollowBot will stay one meter behind the user. | M5 | … | 
| The FollowBot will recognize simple voice commands (i.e., “Stop”, “Go to…”) and respond appropriately. | M6 | … | 
| The user can access the application regardless of platform. | M7 | … | 
| The application will constantly update to retrieve information from the FollowBot about its battery life, temperature, and weight. | M8 | Frank |
| The battery life will be able to last for more than 4 hours. | M9 | Frank |
| The user will be able to map the FollowBot from location to location. | M10 | Joseph |
| The user will be able to request a FollowBot from another location to their position via a mapping tool. | M11 | Joseph |
| The FollowBot will rely on computer vision to identify a target user. | M12 | Trong, Joseph |
| The FollowBot will use computer vision for object detection and take appropriate actions for obstacles. | M13 | Trong |
| The FollowBot, in the event of getting stuck, will attempt to self-correct. If it fails, the bot will notify the user and allow manual control. | M14 | … |
| Restricted administrator privileges will allow access to historical data which may be integrated to improve functionalities. | M15 | … |
| The user can be confident in the security of their data, relying on the robust database, authentications, and opting out of data collection. | M16 | … |

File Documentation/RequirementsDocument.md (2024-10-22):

# Requirements Documentation:

<h2> phase 1 </h2>

Specified Goal: Create a prototype that will follow an individual via bluetooth connection

__1. Aquire and upload ROS2 onto a Raspberry pi/Website production:__   
a. Flashing an sd card with UBUNTU OS  
b. Using documentation and instructions within the ROS2 site: https://docs.ros.org/en/jazzy/How-To-Guides/Installing-on-Raspberry-Pi.html to install ROS2  
c. Conducting ssh practices in order to code from a seperate device to the Raspberry PI.  
d. Produce and design the website for finalization for our product.

__2. Creating scripts based on specific parameters and tasks the Followbot will conduct/Website finalization:__    
a. C++ scripts to conduct movement and locative tasks.  
b. Constructing an application within a mobile device to instruct the user what the Followbot is currently doing.  
c. Include a form of networking between both devices.  
d. Finalize and tweak the website to our specifications.

__3. Creating a Machine Learning algorithm in order for the FollowBot to avoid obstacles and pathfind through obstacles.__
a. C++ and Python scripts in order to conduct distancing between the user and the FollowBot.
b. Using lidar sensors, and other sensors to detect objects.
c. Using computer vision in order to detect the user and follow the user.
d. Using encoders to calculate the movement in the wheels.

__3. Construct the design of the Followbot and build the Followbot:__  
a. Use fusion360 to create the design of the Followbot or CAD as another platform to use.  
b. obtaining the specified hardware and parts that is needed to construct the first prototype.  
c. finalize the design of the prototype.  

<h2> phase 2 </h2>    
Specified Goal: Improve the design of the prototye so that it can achieve avoidance and pathfinding through obstacles, and weight distributing tasks. Along with better power usage and a better user friendly interface within mobile devices. (This to be changed when we get closer to phase 2)

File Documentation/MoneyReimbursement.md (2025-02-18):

<h1> Reimbursement for the Team: </h1>

The team will be purchasing certain items for the capstone project based on the different prototype needs.

<h2> Prototype 1 Needs: </h2>

Standoff screws: $9.99
* https://www.amazon.com/gp/product/B0B2WDRK7W/ref=sw_img_1?smid=A2PL6UUXJC5K5G&psc=1

Motor Driver Shield: $7.49
* https://www.amazon.com/HiLetgo-Driver-Shield-Compatible-Duemilanove/dp/B01DG61YRM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

Adhesive Velcro Wraps: $4.99
* https://www.amazon.com/Adhesive-Square-Strips-Fastener-Outdoor/dp/B0D1KNBRJB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

4 x AA Battery Holder: $2.95
* https://www.adafruit.com/product/3859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

M3 Screws: $4.99
* https://www.amazon.com/Washers-Sutemribor-Assortment-Stainless-Threaded/dp/B0CP7Y7M6D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

Arduino Rev4 Wifi: $27.50
* https://store-usa.arduino.cc/products/uno-r4-wifi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

USB to USB C Adapater: $5.99
* https://www.amazon.com/dp/B0BJ8YQ2LM?ref=ppx_yo2ov_dt_b_fed_asin_title&th=1

USB C to quick wire cable connector: $7.99
* https://www.amazon.com/dp/B0CLH7FR8V?ref=ppx_yo2ov_dt_b_fed_asin_title&th=1

Battery Pack 10400mAh: $13.99
* https://www.amazon.com/dp/B0B7XNNJJB?ref=ppx_yo2ov_dt_b_fed_asin_title

Infrared Sensors IR: $7.70
* https://www.amazon.com/gp/product/B0B74QJV8H/ref=ppx_yo_dt_b_asin_title_o00_s00?ie=UTF8&psc=1

Mecanum Wheel 48mm Omni Directional Electric: $15.79
* https://www.amazon.com/gp/product/B0B6GLYLHZ/ref=ppx_yo_dt_b_asin_title_o01_s00?ie=UTF8&psc=1

Raspberry Pi 4B 2GB RAM + Micro-HDMI + Official Raspberry Pi Case + Official Raspberry Pi power charger: $75.90
* https://www.adafruit.com/product/4296

Motors with Encoders: $14.88 
* https://tinyurl.com/48wfdm87

Gyroscope: $6.99
* https://tinyurl.com/2yp4y88m

Cheap Camera: $35.99
* https://tinyurl.com/yd8knfjm

Raspberry Pi 5: $72.99
* https://tinyurl.com/y4cyc9cp 

NVME drive for the Pi: $12.90
* https://tinyurl.com/3h4cp4h5 

<h3> Total Cost + Tax: $344.02 </h3>

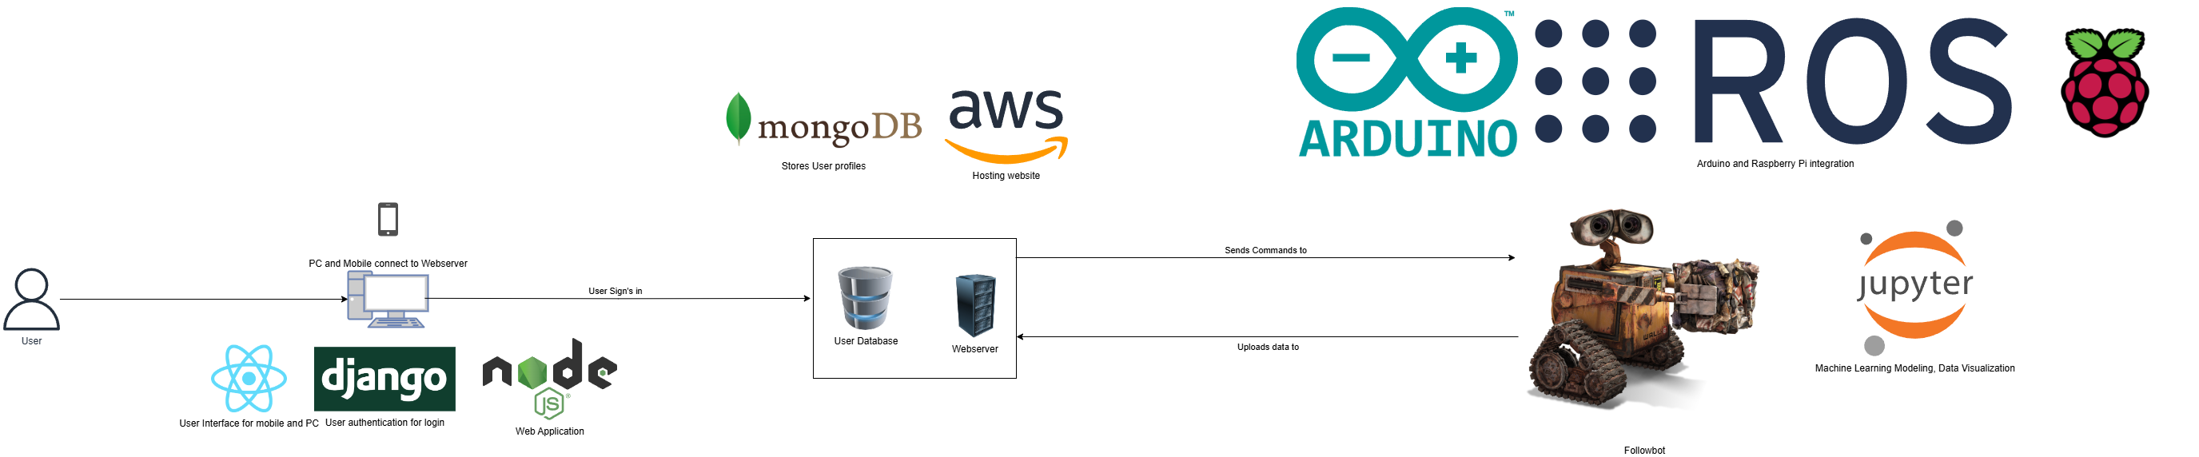
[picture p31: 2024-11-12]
Images/High_Level_Design_Architecture.png

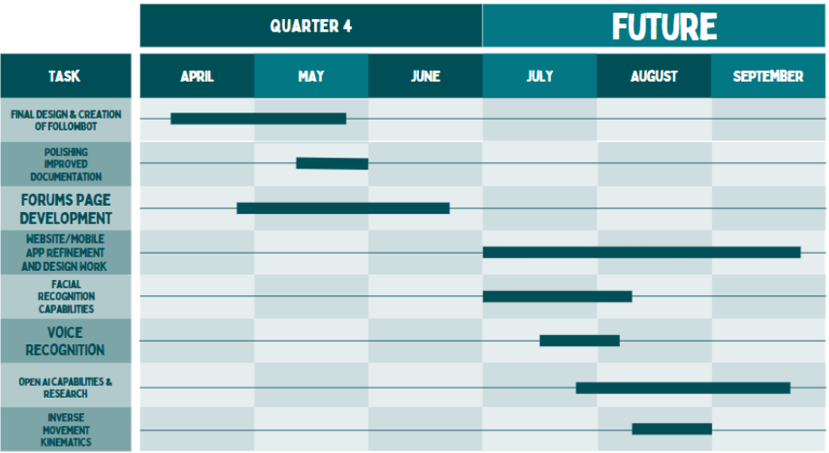
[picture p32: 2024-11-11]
Images/Timeline3.png

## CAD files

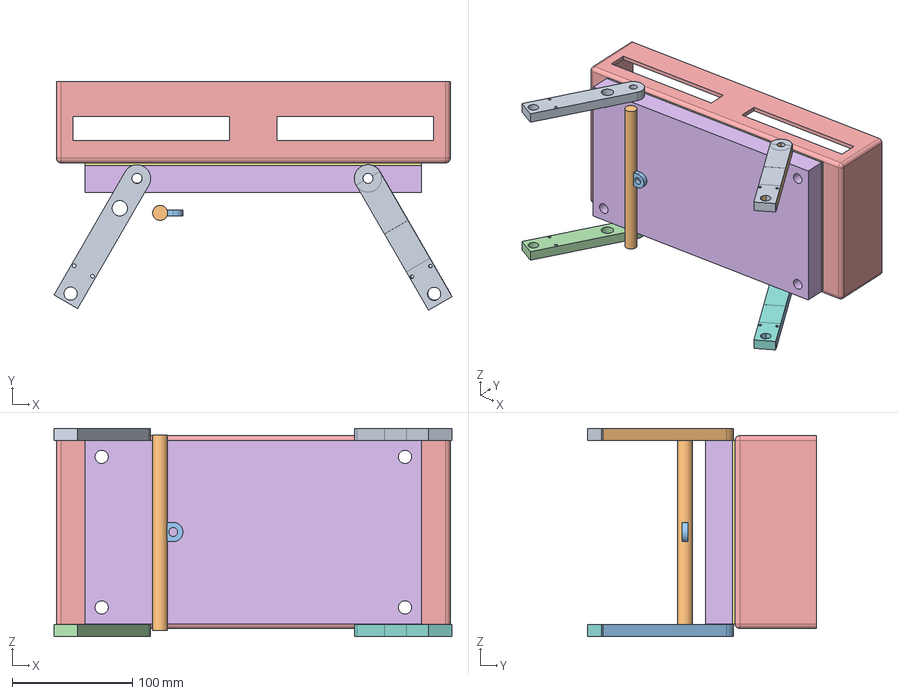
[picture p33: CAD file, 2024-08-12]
FollowBot_Prototype1.FCStd
330.6 x 189.8 x 173.0 mm
Leg1
Leg2
Leg3
Leg4
RobotShell
Holder
extensionOfHolder
unattendedLeg2
unattendedLeg

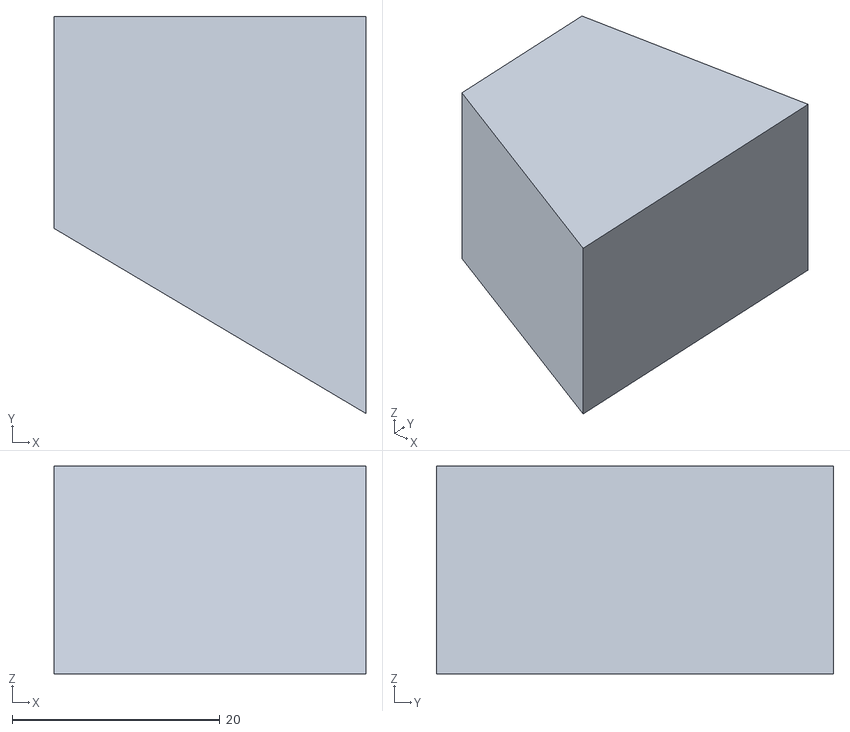
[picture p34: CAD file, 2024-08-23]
Prototypes/Prototype1/3D prints/DoorStops/FollowBot_Prototype1-FrontDoorStop.stl
30.0 x 38.2 x 20.0

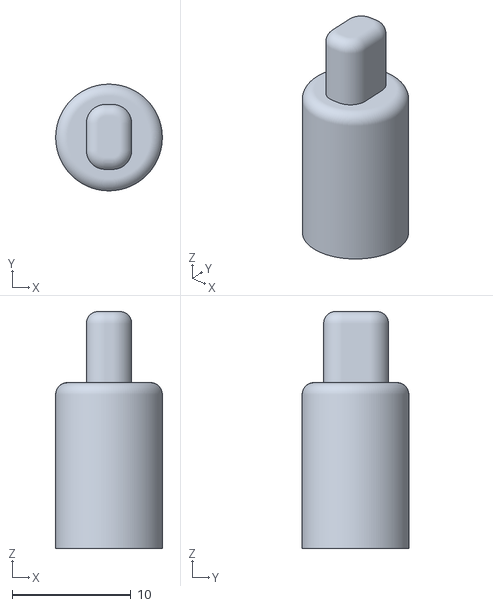
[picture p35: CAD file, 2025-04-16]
Prototypes/Prototype1/3D prints/Encoders/MotorToWheel.stl
9.00 x 9.00 x 20.0

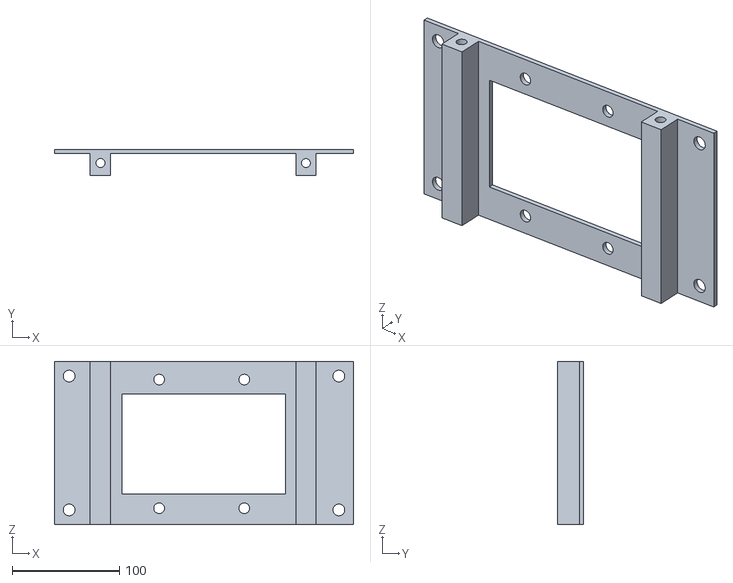
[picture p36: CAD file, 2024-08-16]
Prototypes/Prototype1/3D prints/FollowBot_Prototype1-LegHolderBody.stl
279.3 x 24.4 x 152.4

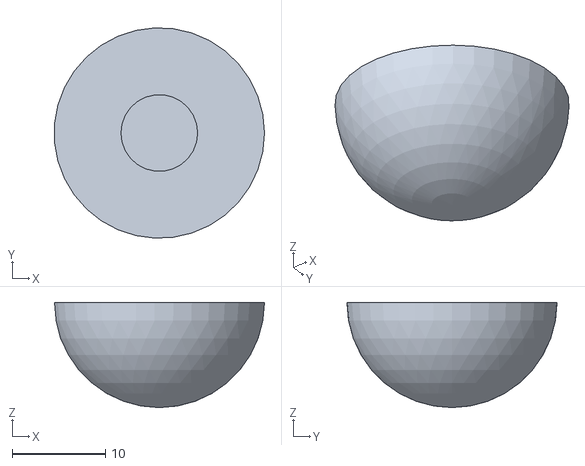
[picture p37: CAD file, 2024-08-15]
Prototypes/Prototype1/3D prints/Leg Rod/FollowBot_Prototype1-Rod Stabalizer Body.stl
22.6 x 22.6 x 11.3

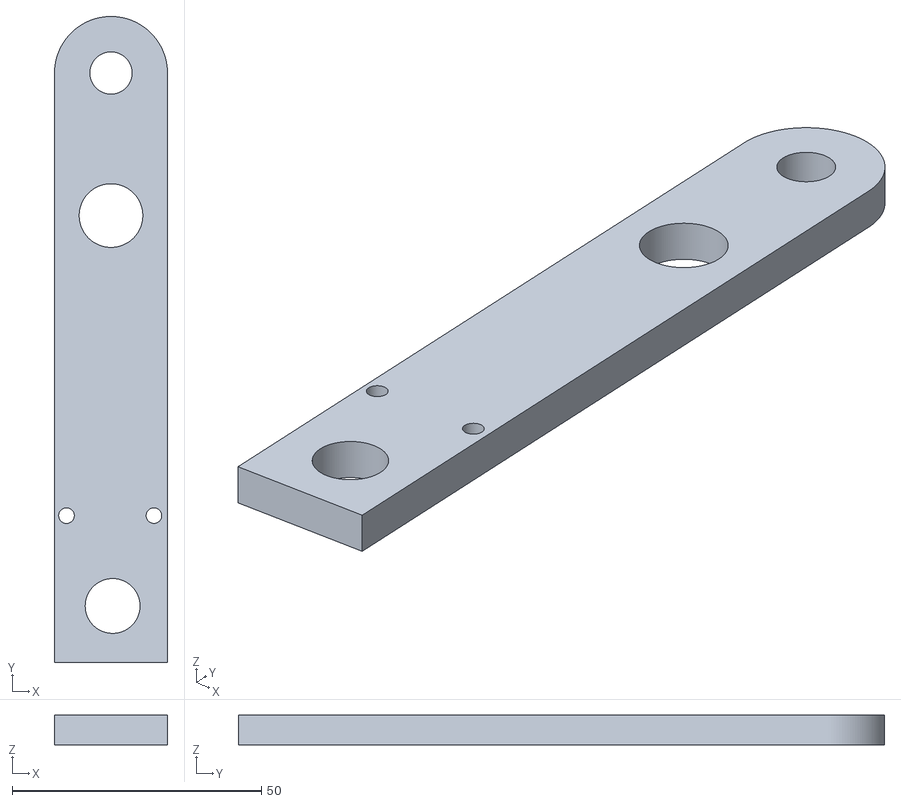
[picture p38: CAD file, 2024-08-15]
Prototypes/Prototype1/3D prints/legs/FollowBot_Prototype1-Leg GroupLeg2.stl
22.7 x 129.7 x 6.00

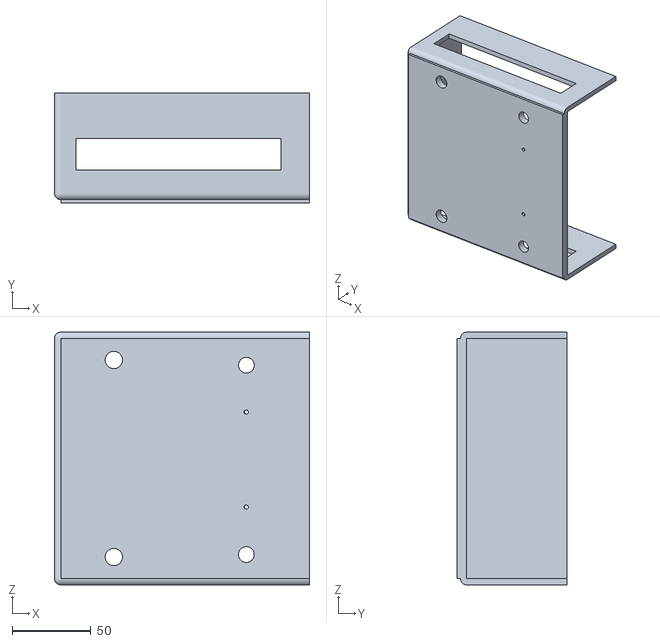
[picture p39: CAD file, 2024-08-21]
Prototypes/Prototype1/3D prints/RobotChassis/FollowBot_Prototype1-RobotChassisBodyPart2.stl
161.8 x 69.5 x 160.4

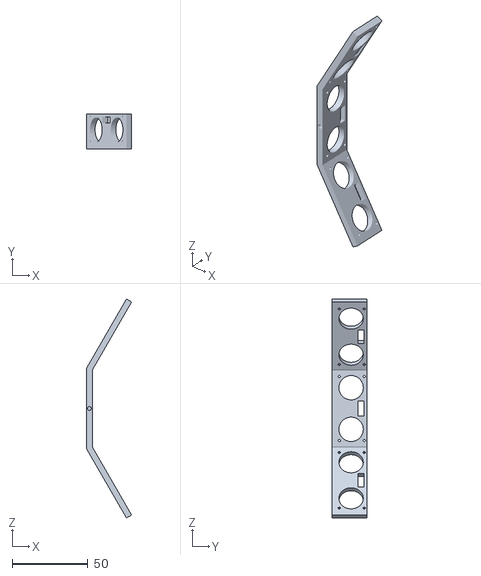
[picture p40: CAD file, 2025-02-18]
Prototypes/Prototype1/3D prints/SensorSpecifics/FollowBot_Prototype1-SensorPartsV_1SensorFrameV_1.stl
29.9 x 23.0 x 144.8

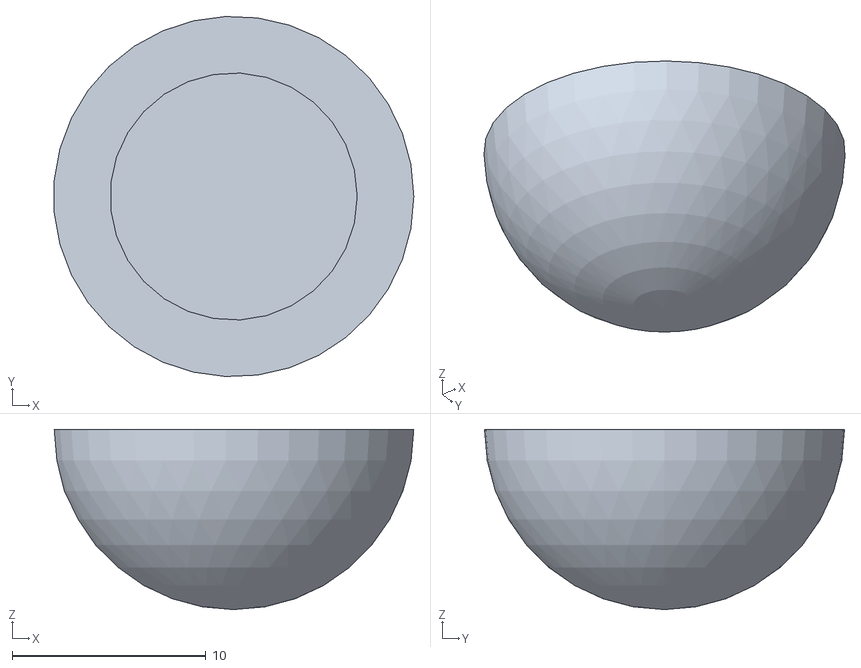
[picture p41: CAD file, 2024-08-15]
Prototypes/Prototype1/3D prints/tensionRod/FollowBot_Prototype1-tensionRod Stabalizer.stl
18.6 x 18.6 x 9.30

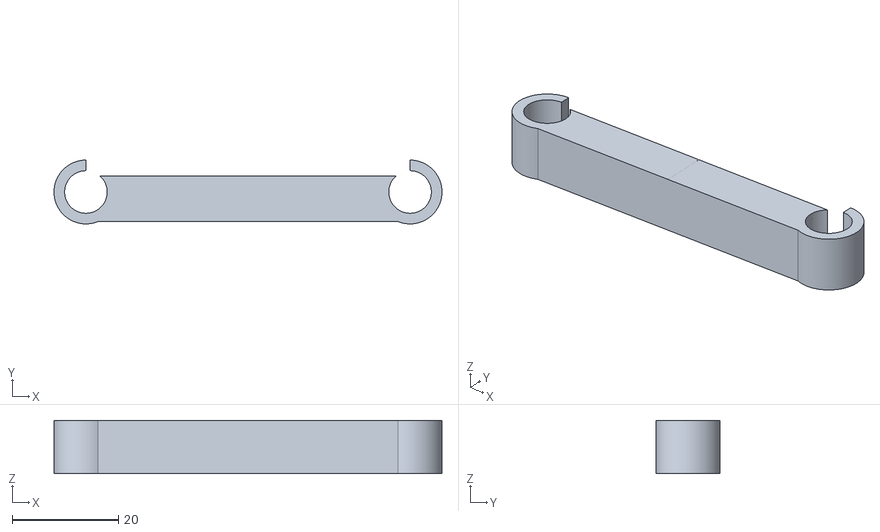
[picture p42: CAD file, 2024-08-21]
Prototypes/Prototype1/3D prints/TensionStabalizer/FollowBot_Prototype1-TensionHolder.stl
72.9 x 12.0 x 10.0

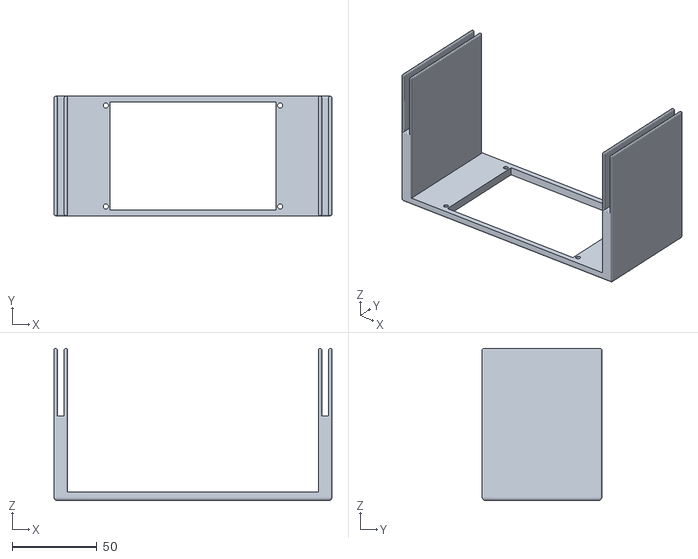
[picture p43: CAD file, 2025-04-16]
Prototypes/Prototype1/3D prints/TFT Display/TFT Display Holder.stl
164.4 x 70.7 x 90.0

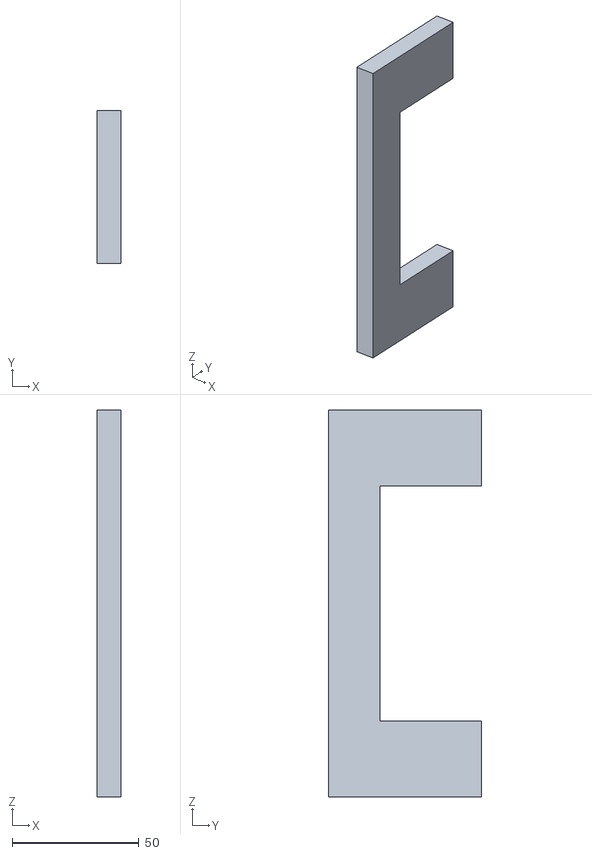
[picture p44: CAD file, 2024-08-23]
Prototypes/Prototype1/3D prints/DoorStops/FollowBot_Prototype1-refine_DoorStop1.stl
9.52 x 60.4 x 152.4

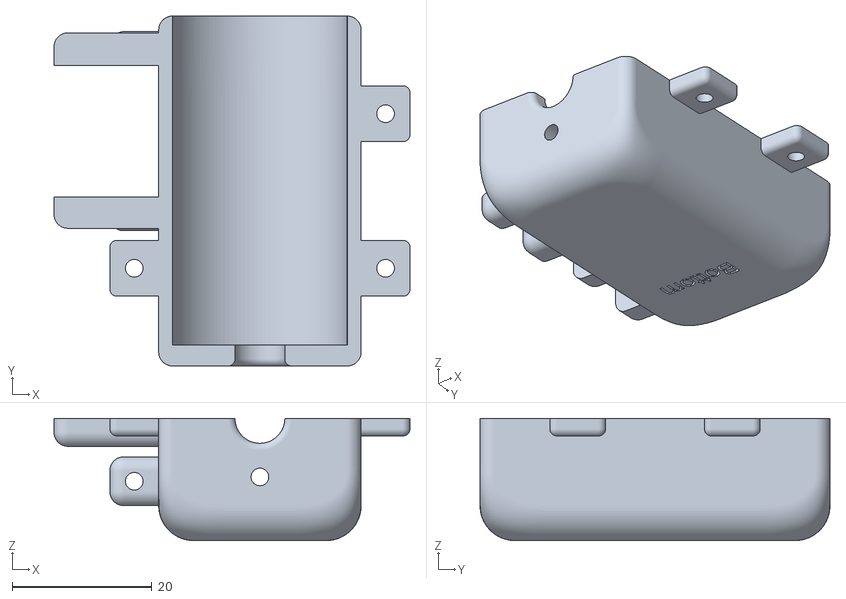
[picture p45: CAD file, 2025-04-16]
Prototypes/Prototype1/3D prints/Encoders/MotorHolderBottom.stl
51.0 x 50.1 x 17.5

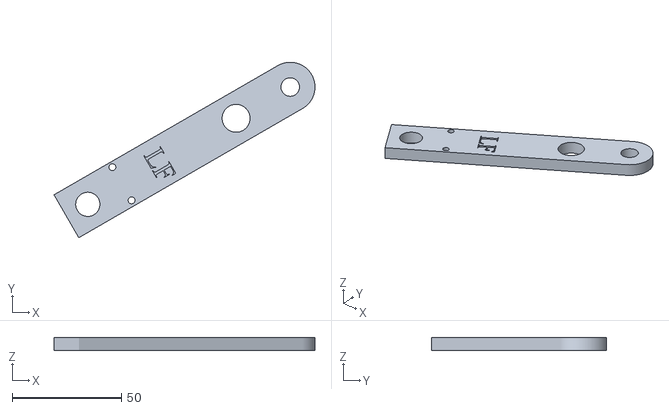
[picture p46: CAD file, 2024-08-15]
Prototypes/Prototype1/3D prints/legs/FollowBot_Prototype1-Leg GroupLeg1.stl
119.5 x 80.3 x 6.00

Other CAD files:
Prototypes/Prototype1/3D prints/Leg Rod/FollowBot_Prototype1-Rod Stabalizer Body2.stl
Prototypes/Prototype1/3D prints/RobotChassis/FollowBot_Prototype1-ChassisPart1.stl
Prototypes/Prototype1/3D prints/SensorSpecifics/FollowBot_Prototype1-SensorPartsV_1FrameHolder.stl
Prototypes/Prototype1/3D prints/DoorStops/FollowBot_Prototype1-refine_DoorStop2.stl
Prototypes/Prototype1/3D prints/Encoders/LegHolderBottom.stl
Prototypes/Prototype1/3D prints/Encoders/LegHolderTop.stl
Prototypes/Prototype1/3D prints/Encoders/MotorHolderTop.stl
Prototypes/Prototype1/3D prints/Encoders/TFT Display Holder.stl
Prototypes/Prototype1/3D prints/Screws/FollowBot_Prototype1-M12-Nut.stl
Prototypes/Prototype1/3D prints/Screws/FollowBot_Prototype1-M12-Washer.stl
Prototypes/Prototype1/3D prints/SensorSpecifics/FollowBot_Prototype1-SensorPartsV_1SensorFrameV_1UPDATED.stl
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

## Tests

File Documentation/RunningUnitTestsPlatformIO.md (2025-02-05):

# Running Unit Tests with PlatformIO

To ensure your unit tests and source code run correctly, follow these steps:

### Configuration

**1. Add the Native Environment for Unit Testing:** In your `platformio.ini` file, include a `[env: native]` section for running Unity tests.:

```ini
[env:native]
platform = native
test_framework = unity
```

**2. Ensure Your Hardware Environment is Configured:** Include  the relevant hardware environment configuration, such as `uno-r4_wifi`, in your platformio.ini` file.

```ini
[env:uno_r4_wifi] 
platform = renesas-ra 
board = uno_r4_wifi 
framework = arduino 
lib_deps = 
    adafruit/Adafruit Motor Shield V2 Library@^1.1.3 
    SPI adafruit/DHT sensor library@^1.4.6 
    adafruit/Adafruit Unified Sensor@^1.1.14 
    bblanchon/ArduinoJson@^7.1.0 
    TFT_eSPI 
    openagriculturefoundation/rosserial_arduino@0.0.0-alpha+sha.1834b766b0 
    throwtheswitch/Unity@^2.6.0
```

### Running the Tests

**1. Run Unit Tests:** To run your unit tests with the native environment, use the following command:

```sh
pio test -e native
```

**2. Compile and Upload Source Code:** To compile and upload your source code for the specified hardware environment, use:

```sh
pio run -e uno_r4_wifi
```

When it comes to uploading code to a specific board, it get's quite annoying to see the native environment fail over and over again since it's meant for unit testing nothing else. That is why it is best to upload the code specifically to the board through this pio command:

```sh
platformio run --target upload --environment uno_r4_wifi
```

Following these instructions will help ensure your unit tests and source code are handled in the correct environments.

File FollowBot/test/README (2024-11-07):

This directory is intended for PlatformIO Test Runner and project tests.

Unit Testing is a software testing method by which individual units of
source code, sets of one or more MCU program modules together with associated
control data, usage procedures, and operating procedures, are tested to
determine whether they are fit for use. Unit testing finds problems early
in the development cycle.

More information about PlatformIO Unit Testing:
- https://docs.platformio.org/en/latest/advanced/unit-testing/index.html

Note:
to run your test within the test directory you will need to type this in your shell: pio test -e native

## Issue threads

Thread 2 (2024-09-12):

Clicking rapidly causes robot to frenzy

FrankVanris2, 2024-09-12:
When you click the specific buttons on the webpage, the robot will begin to spasm and go in different directions OR go in only one direction continuously.

FrankVanris2, 2024-09-16:
Fixed issue by removing countless delays on the robot side. I still needed some minor delays but I made them a 10th of a second in order for the delays to not have a major impact when pressing buttons rapidly. Only flaw is that the server we are using to control robot is pretty slow due to it being a python server. Won't be able to change that but it's good to keep that in mind for future changes.

Closed 2024-09-16.

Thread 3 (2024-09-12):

Connection to Server from Robot Disconnects

FrankVanris2, 2024-09-12:
Connection from robot to server does not occur first. Robot connection occurs only when uploading code.

FrankVanris2, 2024-09-12:
*Fix:* When building server/website you'll ALSO need to reset the Robot in order for it to connect again.

*How:** When rebuilding server click the reset button ON the device itself.

FrankVanris2, 2024-09-12:
This is now fixed, if any more issues occur I will open this up again.

Closed 2024-09-12.

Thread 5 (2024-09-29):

500 error for obtaining temp and heat index data when starting program

FrankVanris2, 2024-09-29:
When data is None it gives a 500 error due to no connection to the temp module when starting the program.

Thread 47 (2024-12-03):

Motors Hiccup

FrankVanris2, 2024-12-03:
Sadly there is a bug where the motors will have a hiccup when it comes to obtaining the next directions. This could potentially effect our presentation because it could happen then.

IgorJanGit, 2025-05-13:
okay AI answer
"1. Communication & Code Conflicts
ChiefDelphi Thread: Discusses motor stalling when enabling the driver station, particularly in wireless (radio) vs. tethered (USB) connections. Highlights code conflicts (e.g., competing motor commands) and CAN bus issues as root causes.
Link: [Motors stall when driver station is enabled (Urgent)](https://www.chiefdelphi.com/t/motors-stall-when-driver-station-is-enabled-urgent/494273) 1.

2. Network & Radio Interference
FRC Known Issues: Addresses driver station disables due to wireless interference, bandwidth saturation, or radio placement. Recommends relocating radios away from motors/metal and testing wired connections.
Link: [FIRST Robotics Known Issues](https://docs.wpilib.org/en/stable/docs/yearly-overview/known-issues.html) 17.

3. Computer/Driver Compatibility
Talkshopbot Forum: Highlights hardware compatibility issues (e.g., Dell PCs causing USB/serial communication delays). Suggests testing with alternative computers or updating drivers.
Link: [X/Y Motors Stalling](https://www.talkshopbot.com/forum/printthread.php?t=12062&pp=10&page=3) 10.

4. Power Delivery & PTC Fuses
Vamfun’s Blog: Explains how abrupt motor reversals or high torque loads can trip PTC fuses (current-limiting devices) in motor controllers, causing stalls. Relevant if your motors draw excess current during communication gaps.
Link: [Robot Drive Train Stalling](https://vamfun.wordpress.com/2011/11/22/note-robot-drive-train-stalling/) 9.

5. Motor Hardware Failures
VEX Forum: Discusses 11W motor stalling due to internal gear/bearing issues. While less likely in your case, it’s worth ruling out mechanical binding or motor wear.
Link: [11W Motor Stalling](https://www.vexforum.com/t/11w-motor-stalling/118039) 13.

Additional Resources
REV Motor Specifications: Details motor efficiency, stall torque, and overheating risks. Useful for understanding motor limits under communication delays.
Link: [DUO Build System Motors](https://docs.revrobotics.com/duo-build/motion/motors) 11.
" will look more of issue

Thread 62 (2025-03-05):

Hidden password on Robotic UI

FrankVanris2, 2025-03-05:
The password should have a hidden feature so that the user or any user won't be able to see the password that is currently used in order to login to the Network

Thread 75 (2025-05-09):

Add Error screen for development purposes

FrankVanris2, 2025-05-09:
Add an error screen where if something wrong occurred during the idle transition. It would send an error message to the tft screen. Currently the Idle Screen is very basic.

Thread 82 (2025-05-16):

Create a Circular buffer to remove the buffer overloading on the Arduino board.

FrankVanris2, 2025-05-16:
In order to prevent buffer overloading from occurring we will need to create a circular buffer on the arduino side to prevent the buffer from overloading. Especially when everything is running as a Singleton.

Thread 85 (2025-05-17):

The connection to the server dies ranging between 5-20 minutes

FrankVanris2, 2025-05-17:
The connection to the server some how dies after a couple of minutes. I don't know why but it's definitely something we need to fix

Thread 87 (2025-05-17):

Memory check error

FrankVanris2, 2025-05-17:
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

Did an inspect on the project, we will need to resolve these 2 main errors still. Could cause serious issues to the project when it comes to memory.

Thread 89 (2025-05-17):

TFT Screen mode change issue

FrankVanris2, 2025-05-17:
When clicking on the user control button of the website, It switches to the manual mode screen, but then back to the following mode screen for some reason. And it does the same thing for when you switch to following mode it's on manual mode.

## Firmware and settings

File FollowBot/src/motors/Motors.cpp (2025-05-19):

/*
* By: Frank Vanris
* Date: 8/17/2024
* Desc: A motor class that will store all the types of motors that will be used
* for this project.
*/
#include <Arduino.h>
#include <Wire.h>
#include <Adafruit_MotorShield.h>

#include "Motors.h"
#include "objectavoidance&detection/ObjectAvoidance.h"
#include "states&types/MotorControlStates.h"
#include "followbot_manager/FollowBotManager.h"

const int MAX_SPEED = 255;
const int MED_SPEED = 200;
const int LOW_SPEED = 150;
const int MIN_EFFECTIVE = 50;

const int ANGLE_THRESHOLD = 45; // degrees

// Universal Object
Motors myMotors;

// Create motor shield object with the default 12C address
Adafruit_MotorShield motorShield = Adafruit_MotorShield();

// Select which port
Adafruit_DCMotor *motor1 = motorShield.getMotor(1);
Adafruit_DCMotor *motor2 = motorShield.getMotor(2);
Adafruit_DCMotor *motor3 = motorShield.getMotor(3);
Adafruit_DCMotor *motor4 = motorShield.getMotor(4);

// My constructor
Motors::Motors(): mCurrentDirection(MOTOR_STOP) {}

void Motors::motorSetup() {
    Serial.println("Motor Setup");

    if (!motorShield.begin()) {             // create with the default frequency 1.6KHz
        // if (!motorShield.begin(1000)) {  // OR with a different frequency, say 1KHz
        Serial.println("Could not find Motor Shield. Check wiring.");
        while (1);
    }
    Serial.println("Motor Shield found.");
    
    //setting speeds of all motors to high
    motor1->setSpeed(MED_SPEED);
    motor2->setSpeed(MED_SPEED);
    motor3->setSpeed(MED_SPEED);
    motor4->setSpeed(MED_SPEED);
}

// TODO: change to new
void Motors::motorLoop() {
  if(mNewDirection != mCurrentDirection) {
       Serial.print("Motors.motorLoop - Updated Motor Direction: ");
       Serial.println(mNewDirection);
      mCurrentDirection = mNewDirection;
      adjustDirection();
  }

    // Serial.println("test1 left wheel");
    // setLeftRightSpeeds(100, 0);
    // delay(2000);
    // motorStop();

    // Serial.println("test1 right wheel");
    // setLeftRightSpeeds(0, 100);
    // delay(2000);
    // motorStop();

    // Serial.println("test2");
    // myMotors.setNormalizedSpeeds(0.3, 0.3);
    // delay(2000);

    // Serial.println("test3");
    // myMotors.setNormalizedSpeeds(1.0, 1.0);
    // delay(2000);

    // Serial.print("stop");
    // setNormalizedSpeeds(0, 0);
    // delay(2000);
}

int Motors::scaleSpeed(float normalized) {
    // map [-1.0, 1.0] to [MIN_SPEED, MAX_SPEED]
    return constrain(
        (abs(normalized) * (MAX_SPEED - MIN_EFFECTIVE)) + MIN_EFFECTIVE,
        MIN_EFFECTIVE,
        MAX_SPEED
    ) * (normalized > 0 ? 1 : -1);
}

void Motors::setNormalizedSpeeds(float left, float right) {
    setLeftRightSpeeds(
        scaleSpeed(left),
        scaleSpeed(right)
    );
}

void Motors::setLeftRightSpeeds(int leftSpeed, int rightSpeed) {
    // left side motors (1 & 4)
    setMotorDirection(motor1, leftSpeed);
    setMotorDirection(motor4, leftSpeed);

    // right side motors (2 & 3)
    setMotorDirection(motor2, rightSpeed);
    setMotorDirection(motor3, rightSpeed);

    // set speeds after setting direction
    motor1->setSpeed(constrain(abs(leftSpeed), MIN_EFFECTIVE, MAX_SPEED));
    motor4->setSpeed(constrain(abs(leftSpeed), MIN_EFFECTIVE, MAX_SPEED));
    motor2->setSpeed(constrain(abs(rightSpeed), MIN_EFFECTIVE, MAX_SPEED));
    motor3->setSpeed(constrain(abs(rightSpeed), MIN_EFFECTIVE, MAX_SPEED));
}

void Motors::setMotorDirection(Adafruit_DCMotor* motor, int speed) {
    if(speed > 0) {
        motor->run(FORWARD);
    } else if(speed < 0) {
        motor->run(BACKWARD);
    } else {
        motor->run(RELEASE);
    }
}

/** BEGINNING OF LEGACY FUNCTIONS: */
void Motors::setMotorSpeed(int leftSpeed, int rightSpeed) {
    motor1->setSpeed(leftSpeed);
    motor2->setSpeed(rightSpeed);
    motor3->setSpeed(rightSpeed);
    motor4->setSpeed(leftSpeed);
    motorForwards();
}

// testing client, (very important)
void Motors::adjustDirection() {
    if (mUseVelocity) return; // skip if using new control

    Serial.println(String("Motors.adjustDirection - Current Direction: ") + mCurrentDirection); 
    if (mCurrentDirection == MOTOR_FORWARD) {
        motorForwards();
    } else if (mCurrentDirection == MOTOR_BACKWARD) {
        motorBackwards();
    } else if (mCurrentDirection == MOTOR_LEFT) {
        motorLeft();
    } else if (mCurrentDirection == MOTOR_RIGHT) {
        motorRight();
    } else if (mCurrentDirection == MOTOR_STOP) {
        motorStop();
    }
}

void Motors::turn(float turn) {
    if (turn > ANGLE_THRESHOLD) {
        motorRight();
    } else if (turn < -ANGLE_THRESHOLD) {
        motorLeft();
    } else {
        motorForwards();
    }
}

void Motors::moveForward() {
    motorForwards();
}

void Motors::moveBackward() {
    motorBackwards();
}

void Motors::stopMoving() {
    motorStop();
}

// Forward motion with the motors
void Motors::motorForwards() {
    Serial.println("Motors.motorForwards()");
    motor1->run(FORWARD);
    motor2->run(FORWARD);
    motor3->run(BACKWARD);
    motor4->run(BACKWARD);
}

// Backward motions with the motors
void Motors::motorBackwards() {
    Serial.println("Motors.motorBackwards()");
    motor1->run(BACKWARD);
    motor2->run(BACKWARD);
    motor3->run(FORWARD);
    motor4->run(FORWARD);
}

// Left motions with the motors
void Motors::motorLeft() {
    Serial.println("Motors.motorLeft()");
    motor1->run(BACKWARD);
    motor2->run(FORWARD);
    motor3->run(BACKWARD);
    motor4->run(FORWARD);
}

// Right motions with the motors
void Motors::motorRight() {
    Serial.println("Motors.motorRight()");
    motor1->run(FORWARD);
    motor2->run(BACKWARD);
    motor3->run(FORWARD);
    motor4->run(BACKWARD);
}

void Motors::motorStop() {
    Serial.println("Motors.motorStop()");
    motor1->run(RELEASE);
    motor2->run(RELEASE);
    motor3->run(RELEASE);
    motor4->run(RELEASE);
}
/** END OF LEGACY FUNCTIONS: */

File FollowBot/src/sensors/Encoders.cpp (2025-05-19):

/*
 * Encoders.cpp
 * By: Frank Vanris
 * Date: 4/10/2025
 * Desc: Implementation for wheel rotation encoders.
 * 
 * Hardware Notes:
 * - The wheel encoders provide 48 CPR (counts per revolution)
 * - IMPORTANT: Encoder 1 (mPosition1) is connected to the RIGHT motor
 * - IMPORTANT: Encoder 2 (mPosition2) is connected to the LEFT motor
 * - Encoders use quadrature output (A & B channels) to detect direction
 */

#include "Encoders.h"
#include "config.h"
#include <Arduino.h>

// Singelton instance
Encoders encoders;

// Initialize static variables
volatile double Encoders::mPositionRight = 0.0; // RIGHT motor position
volatile double Encoders::mPositionLeft = 0.0; // Left motor position

/**
 * Constructor - initializes counter and timing variables
 */
Encoders::Encoders() : 
    currentTime(0), 
    previousTime(0),
    previousPositionRight(0), 
    previousPositionLeft(0) 
{
    // Initialize encoder data array
    for (int i = 0; i < DATA_SIZE; i++) {
        encoderData[i] = 0.0;
    }
}

/**
 * Configure encoder pins and attach interrupt handlers
 */
void Encoders::setupEncoders() {
    // Set pin modes for encoder inputs
    pinMode(ENCODER_OUT_A, INPUT);      // RIGHT encoder channel A
    pinMode(ENCODER_OUT_B, INPUT);      // RIGHT encoder channel B
    pinMode(ENCODER_OUT_A2, INPUT);     // LEFT encoder channel A
    pinMode(ENCODER_OUT_B2, INPUT);     // LEFT encoder channel B

    // Attach interrupt handlers for both encoders
    // RISING edge triggers an interrupt when the signal goes from low to high
    attachInterrupt(digitalPinToInterrupt(ENCODER_OUT_A), readEncoderRight, RISING);
    attachInterrupt(digitalPinToInterrupt(ENCODER_OUT_A2), readEncoderLeft, RISING);

    // Initialize timing
    previousTime = micros();
}  

/**
 * Process encoder data at regular intervals
 */
void Encoders::loopEncoders() {

    // Get current time in microseconds
    currentTime = micros();
    
   // Only update data at regular intervals (every UPDATE_INTERVAL milleseconds)
    if(currentTime - previousTime >= THREE_SECONDS) {
        // Save current tick counts to data array
        setEncoderData(mPositionRight, mPositionLeft);

        // Debug output (uncomment when needed)
        // Serial.println("Encoder data updated:");
        // Serial.println("  RIGHT motor (Encoder 1): " + String(mPosition1) + " ticks");
        // Serial.println("  LEFT motor (Encoder 2): " + String(mPosition2) + " ticks");
   
        // Save current position for next cycle
        previousPositionRight = mPositionRight;
        previousPositionLeft = mPositionLeft;

        // Reset counters for next interval
        mPositionRight = 0;
        mPositionLeft = 0;

        // Update time for next interval
        previousTime = currentTime;
    }
}

/**
 * Interrupt service routine for RIGHT motor encoder (Encoder 1)
 * Called on RISING edge of channel A
 */
void Encoders::readEncoderRight() {
    // Read channel B to determine direction
    int b = digitalRead(ENCODER_OUT_B);

    // Update position based on direction
    if (b == HIGH) {
        mPositionRight++;   // Forward rotation
    } else {
        mPositionRight--;   // Reverse rotation
    }
}

/**
 * Interrupt service routine for LEFT motor encoder (Encoder 2)
 * Called on RISING edge of channel A
 * 
 * Note: Direction is inverted compared to RIGHT encoder due to 
 * physical mounting orientation of the LEFT motor and encoder
 */
void Encoders::readEncoderLeft() {
    // Read channel B to determine direction
    int b = digitalRead(ENCODER_OUT_B2);

    // Direction is inverted for left motor due to physical mounting
    if (b == HIGH) {
        mPositionLeft--;   // Forward rotation (inverted)
    } else {
        mPositionLeft++;   // Reverse rotation (inverted)
    }
}

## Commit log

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2024-07-12 Create FollowBot_Prototype1.FCStd
    Created the FreeCAD file for our first prototype for our robot. We will use this environment to design and create our first version of our robot that will follow these guidelines:
    * Follow the user
    * small and sturdy
    [FollowBot_Prototype1.FCStd]
2024-08-08 Included the necessary files for Arduino
    These files will be needed in order to run our robot properly. Used Platform IO in order to write to the arduino properly. Created a new project FollowBot, currently has the necessary setup for us to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
2024-08-08 updated prototype1 design
    worked on the design for prototype1
    [FollowBot_Prototype1.FCStd]
2024-08-09 Updated FollowBot_Prototype
    designed the first 2 legs, will make copies of those legs as well.
    [FollowBot_Prototype1.FCStd]
2024-08-10 updated the prototype design
    the design now has a shell and a full set of legs,
    changes will need to be added in order to add
    [FollowBot_Prototype1.FCStd]
2024-08-10 added server with react/python
    added the server with react/python that will be used to interact with the robot.
    [FollowBot_Prototype1.FCStd]
2024-08-12 prototype1 changes
    adding more requirements to the prototype
    [FollowBot_Prototype1.FCStd]
2024-08-12 Created PROPER legs
    I needed to redesign the legs due to the fact there were many components previously created with it, which caused a lot of print issues, now we have fluid redesigned legs using part design from freeCAD instead of just using part, like i previously did.
    [FollowBot_Prototype1.FCStd]
2024-08-13 Updated Prototype Design
    Added a station for the arduino, sliced the chassis of the robot, and added a few more holes for the platter.
2024-08-13 3d prints that could change
    3d print for the arduino holder, and simple corkscrew
    [FollowBot_Prototype1-CorkScrew.stl]
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2024-08-14 Prototype1 changes
    Changed the pipes and the screws sizes
    [FollowBot_Prototype1-CorkScrew.stl, FollowBot_Prototype1-CorkScrewSimple.stl, FollowBot_Prototype1-CorkScrewSimpleCircularNut.stl]
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2024-08-14 new prints for leg group
    leg group prints
    [FollowBot_Prototype1-Leg GroupLeg1.stl, FollowBot_Prototype1-Leg GroupLeg2.stl, FollowBot_Prototype1-Leg GroupLeg3.stl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]
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2024-08-15 Documentation Requirements update, as well as leg model updates
    Updated the documentation, as well as the leg models.
    [FollowBot_Prototype1-Leg GroupLeg1.stl, FollowBot_Prototype1-Leg GroupLeg2.stl, FollowBot_Prototype1-Leg GroupLeg3.stl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]
2024-08-15 changes to the design and document
    changed the design of the legs again, while also adding more to the documentation.
    [FollowBot_Prototype1-Leg GroupLeg1.stl, FollowBot_Prototype1-Leg GroupLeg2.stl, FollowBot_Prototype1-Leg GroupLeg3.stl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]
2024-08-16 Documentation updates have been added
    More is to come for the documentation side but we are close to finishing.
    [FollowBot_Prototype1-CorkScrewSimpleCircularNut.stl, FollowBot_Prototype1-LegHolderBody.stl]
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2024-08-20 created designs for the 10M screws
    3D prints for the 10M screws are created.
    [FollowBot_Prototype1-CorkScrewSimple.stl, FollowBot_Prototype1-CorkScrewSimpleCircularNut.stl, FollowBot_Prototype1-M10-Nut.stl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]
2024-08-21 Server added, updated design of robot, and tested with AP
    Added robot server when we will be creating clients that will connect to the server, updated the design to the robot, as well as tested AP points as robot considered as server. Will change to client 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
    [FollowBot_Prototype1-ChassisPart1.stl, FollowBot_Prototype1-FitTesting.stl, FollowBot_Prototype1-M10-Nut.stl]
2024-08-21 removed not needed designs
    [FollowBot_Prototype1-FitTesting.stl, FollowBot_Prototype1-M10-Nut.stl, FollowBot_Prototype1-M10-Washer.stl]
2024-08-21 New Robot/Print changes
    Created a file known as FollowBotClient, and removed FollowBotWifi since we want the robot to be as a client and not a server.
    [FollowBot_Prototype1-M12-Nut.stl, FollowBot_Prototype1-M12-Washer.stl, FollowBot_Prototype1-TensionHolder.stl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]
2024-08-21 minor update to prototype1 print
    nothing special
    [FollowBot_Prototype1-RobotChassisBodyPart2.stl]
2024-08-22 Doorstops
    added doorstops to the design which will prevent our legs from overswinging hopefully
2024-08-23 added refined doorstops
    refined doorstops will prevent the robot from overswinging it's legs.
    [FollowBot_Prototype1-refine_DoorStop1.stl, FollowBot_Prototype1-refine_DoorStop2.stl]
2024-08-23 updated the prototype and code
    Code can now get the robot moving from the server
    [FollowBot_Prototype1-FrontDoorStop.stl]
2024-08-26 ObjectAvoidance added
    Added file to be used when planning to do object avoidance.
    [FollowBotClient.cpp, FollowBotManager.cpp, Motors.cpp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]
2024-08-26 added changes to avoidance
    avoidance check added
    [FollowBotManager.cpp, ObjectAvoidance.cpp]
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2024-08-28 Added/Updated Sensors
    Added the temperature sensors in order to tell the user how hot/cold it is within the device. I also improved the supersonic sensors in order to instantly read the response from a users hand as well as other objects around. And added another sensor in the back of the robot to prevent it from backing into a wall.
    [FollowBotManager.cpp, ObjectAvoidance.cpp, TemperatureReader.cpp]
2024-08-30 ObjectDetection Update
    added correctiveness when it came to the sensors. Originally set to zero now set to whenever the sensors begin.
    [ObjectAvoidance.cpp]
2024-08-30 Learning Model
    Added tinyML and created a minor test with the learning model. I can use any learning model and use any dataset in order to obtain decent predictions. As well as corrected some minor instances within my code.
    [iris.csv]
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2024-09-11 Removed the Vite environment
    Was meant for testing purposes. I fixed my current issue so I didn't have to bother.
2024-09-12 Website to Robot
    Connection between Robot and Website finally work. You can easily allow the robot to move when clicking the buttons.
    Bug fix: When building and starting the server, be sure to reset the robot by clicking the reset button on the robot.
    [FollowBotClient.cpp]
2024-09-12 objectAvoidance
    object avoidance created (but it could be better)
    [FollowBotClient.cpp, FollowBotManager.cpp, Motors.cpp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]
2024-09-16 object avoidance changes
    improved the speed when object avoidance is applied. Intelligence needs to be changed drastically.
    [FollowBotClient.cpp, FollowBotManager.cpp, Motors.cpp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]
2024-09-19 Removed Captive Portal
    Removed the Captive Portal since in the loop the slowness was dragging the robot which caused it to stall. Captive portal is not a liable option for automation purposes.
    [FollowBotClient.cpp, FollowBotManager.cpp]
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2024-09-19 Renamed 2 files
    Renamed 2 files because I mistakenly typed a drug name instead of a screen name.
    [FollowBotLCD.cpp]
2024-09-29 posting temp data on website
    Data of temperature and heat index are now visible on website.
    known issues:
    values for temp and heat index are currently not rounded
    values when data is not available causes 500 error, must resolve with a fix later
    data is not updated in real-time, you must always refresh the page.
    [FollowBotClient.cpp]
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2024-12-01 Logic for connection purposes and RSSI value intake
    Due to the server being slow to connect when the server is innaccessible I had to find a way to allow smooth operations when obtaining RSSI values without the influence of the client connection being an issue. I was able to create logic in which I needed to check the connection upon the server 3 times before continuously obtaining the rssi values for 10 seconds then looking for a connection to the server.
    [FollowBotClient.cpp, FollowBotManager.cpp, FollowMechanics.cpp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]
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2024-12-03 added the button functionality and refresh corrections
    The buttons and the obtaining of the temperature information works now. I am able to send the temperature data up to the server and send the direction information back to the robot. When it comes to refreshing the pages it didn't work correctly. So now I was able to add a browserRouter which allows for the refreshment of the pages.
    [FollowBotClient.cpp, Motors.cpp]
2024-12-23 new 3D additions
    created new 3D additions to our first prototype that will be used for testing purposes when it comes to the following mechanics.
    [FollowBot_SensorContainer.stl]
2025-02-04 Basic Following Mechanics have been updated
    The Following Mechanics have been updated
    [FollowBot_Prototype1-SensorPartsV_1FrameHolder.stl, FollowBot_Prototype1-SensorPartsV_1SensorFrameV_1.stl, FollowBot_Prototype1-SensorPartsV_1SensorFrameV_1UPD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]
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2025-02-13 MAJOR CHANGES
    2 pins of our motor driver are completely corrupted due to unknown reasons. I could not figure out this issue until there was an apparent conditional statement that I had to do in order to check if I could begin my motor shield or not. Pins A4 and A5 of the motorshield on the current device are not applicable for current development. (Future: buy a new motorshield). There are currently no solution around this besides buying a new shield sadly. As of this moment the TFT SPI code have been commented out and the following mechanics currently works as stated in the code.
    [FollowBotManager.cpp, FollowMechanics.cpp, Motors.cpp]
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2025-02-20 Updated InputBox
    InputBox had a bug, still need to implement the text within it however.
    [Keyboard.cpp]
2025-02-21 Keyboard/Input Box updated
    Added a better way in pressing specific keys with no redundancy, along with fixing up the input box so that the user can press it without any issues.
    [Keyboard.cpp]
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2025-02-25 Backend implemented
    Implemented the password/ssid storage where when you input an ssid and password it will be saved within the eeprom. After clicking the save button, the information will be saved.
    Minor Bug: When inputting a new ssid or password during the connected phase, it sticks with the previous password and ssid for some reason. Will need to debug more tomorrow. But for now it works as it stands.
    [FollowBotClient.cpp, FollowBotManager.cpp, WiFiCredentials.cpp]
2025-02-26 Finalized-ish the TFT SPI Display with the wifi connection and keyboard functionality
    The TFT Display is good to go when the user inputs ssid and password information into the screen. This will allow the user to input their wifi credentials without going into the code. I fixed up some tedious bugs as well. There is only 1 or 2 left currently. And I optimized some functionalities within my code.
    [FollowBotClient.cpp, FollowBotLCD.cpp, FollowBotManager.cpp]
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2025-03-07 Fixed GPS
    Fixed the GPS where the user needs to use Serial1 in order to use the GPS module.
    [FollowBotManager.cpp, GPS.cpp, ROS2_Serial.cpp]
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2025-03-11 Type error fixes
    posting bot logs from Arduino was coming in as floats which was causing errors
2025-03-11 fixed back button on user analytics
2025-03-11 fixed the back button
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2025-04-04 Major changes, still needs fixing
    needs fixing
    [FollowBotBluetooth.cpp, FollowBotManager.cpp, FollowMechanics.cpp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]
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2025-04-04 created user/robotic functionality fixes
    fixed the changes between User and Robot
    [FollowBotClient.cpp, FollowBotManager.cpp]
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2025-04-11 added the dead reckoning to the code
    The encoders code has dead reckoning, along with new updates to the 3d prints.
    [LegHolderBottom.stl, LegHolderTop.stl, MotorHolderBottom.stl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]
2025-04-13 Encoder Code finalized
    The code for obtaining the ticks of the encoders have been finalized. It will be sent as a Json file to the pi as the rest of the data. Final change and pr is next.
    [TFT Display Holder.stl]
2025-04-15 print updates
    Updated the prints
    [MotorToWheel.stl, TFT Display Holder.stl]
2025-04-15 Encoder Fix
    Both Encoders work properly now.
    [Encoders.cpp, Encoders.h, FollowBotManager.cpp]
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2025-04-21 Remove file with wrong case name
2025-05-08 Created a Battery Reader
    Fixed up the motors and added a battery reader that will be used in order to read how much battery is currently in the machine. This is necessary to know when to charge the battery.
    [BatteryReader.cpp, BatteryReader.h, FollowBotManager.cpp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]
2025-05-09 Updates
    updated the version for the bluetooth since we were using an older android device.
    Also added a battery detector indicator on the tft screen. It's causing a memory leak that I need to fix.
    [BatteryReader.cpp, BatteryReader.h, FollowBotLCD.cpp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]
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2025-05-13 Bug Fixing
    Fixed up the bugs of Josephs code and was able to test out josephs code. He will need to do more fixes.
    [FollowBotClient.cpp, Motors.cpp]
2025-05-13 Fix for the crashing
    I fixed the crashing issues, which should not occur ever again.
    [FollowBotClient.cpp, FollowBotManager.cpp, FollowMechanics.cpp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]
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2025-05-14 Something is wrong
    helllp
    [FollowBotClient.cpp, FollowBotManager.cpp, GPS.cpp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]
2025-05-14 Updated Code
    We are close to fixing the issues
    [FollowBotClient.cpp]
2025-05-14 Bringing Old GPS Code
    Old GPS code is back because it works and it doesn't break.
    [GPS.cpp]
2025-05-14 Bug fixed all of the motion related issues
    Fixed all the current bugs on the motion class that was causing issues with the main code base of FollowBot
    [Encoders.cpp, Encoders.h, FollowBotManager.cpp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]
2025-05-14 fixed Everything
    Trong wuz here
    [Encoders.cpp, Motors.cpp]
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2025-07-05 Removed specific workflows/ updated readme
    I updated the readme to include necessary techniques that are needed to develop
    on this repository, unit testing will be necessary no matter what. Workflows will be replaced with robotic based workflows. Arduino Code most likely will be migrated at somepoint due to the fact that It would be best to deal with new code compared to
    Legacy code.
